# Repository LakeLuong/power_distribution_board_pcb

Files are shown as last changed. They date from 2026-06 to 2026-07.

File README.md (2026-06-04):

# power_distribution_board_pcb
Custom KiCad power distribution PCB that takes in +48V and regulates it down to 5V, 3.3V and 12V through two adjustable Lm760660 buck converters and a Tps62913. I made this for a bigger project I am working on for an underwater FPV drone to power different components such as ESCs which will take in +48V, sensors which takes 3.3V and 5V for my raspberry pi, and 12V for cameras. 





BOM: 

Tps62913	Low current buck converter converting 5V to 3.3V	2	$5.52		

Lm70660	High Current Buck Converter that takes 48V and brings it down to 12V and 5V	2	$13.60		

0805 4mOhm resistors	Current-sense resistors	10	$5.57	

0805 54.9k Ohm resistors	resistor connects from RT to AGND, helps with switching frequency	10	$0.37	

0806 20.5kOhm resistors	En Vulo resistors	10	$0.34	

0805 3.24kOhm resistor	Compensation capacitor for lm760660	10	$0.34	

0805 1 Ohm resistor	Bootstrap resistor	10	$0.51

0805 2.49kOhm resistor	feedback divider resistor	10	$0.34	

0805 4.87kOhm resistor	Feedback divider resistor	10	$0.34		

0805 52.3kOhm resistor	S-CONF resistor	10	$0.34	

0805 31.6kOhm resistor	Resistor divider for feedback	10	$0.58	

0805 100kOhm resistor	UVLO resistor, pull up resistors, etc, to control current flow	25	$0.64		

2.2uH inductor	Stores energy during switching and smooths current	3	$6.61	

Ferrite Bead	Blocks high frequency noise	5	$1.55	

0805 470nF Ceramic Capacitor	Reduce low frequency output noise on the Tps62913	10	$1.24	

0806 0.1uF Ceramic Capacitor	High frequency bypass capacitors	10	$1.07

0805 0.1uF Ceramic Capacitor	Decouples VDDA analog bias rail	10	$0.72	

0805 4.7uF Ceramic Capacitor	bypass/decoupling capacitor for VCC	5	$1.60	

0805 22uf Ceramic Capacitor	Smooths output voltage	10	$3.74	

1210 47uF Ceramic Capacitors	Smooths output voltage from regulator	15	$8.42	

0805 10uF Ceramic Capacitors	Input capacitors to provide short bursts of current to regulator	10	$3.48		

1210 4.7 uF Ceramic Capacitors	Input capacitors to provide short burst of current	10	$8.49		

0805 150pf Ceramic Capacitors	Compensation capacitors, helps buck converter stay stable from high frequency noise	10	$0.85		

1210 22uF Ceramic Capacitor	Gives high frequency noise to GND	10	$4.77

0805 10nF Ceramice Capacitors	bypass and filtering + provide positive power supply through VCC	10	$0.60	

0805 0.047 uF Ceramic Capacitor	Boostrap capacitor for buck converter	10	$1.47	

0805 2200pF SMD Ceramic Capacitor	Decoupling and filtering for 5v rail	10	$0.39

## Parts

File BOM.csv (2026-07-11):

Name | Purpose | Qty | Total (USD) | Unit Cost (USD) | Link | Distributor
Connectors | Connect to different components using physical wires | 10 | $9.55 | $0.9550 | https://www.digikey.com/en/products?keywords=Connectors | Digi-Key
Tps62913 | Low current buck converter converting 5V to 3.3V | 2 | $5.52 | $2.7600 | https://www.mouser.com/c/?q=Tps62913 | Mouser
Lm70660 | High Current Buck Converter that takes 48V and brings it down to 12V and 5V | 2 | $13.60 | $6.8000 | https://www.mouser.com/c/?q=Lm70660 | Mouser
0805 4mOhm resistors | Current-sense resistors | 10 | $5.57 | $0.5570 | https://www.digikey.com/en/products?keywords=0805+4mOhm+resistors | Digi-Key
0805 54.9k Ohm resistors | resistor connects from RT to AGND, helps with switching frequency | 10 | $0.37 | $0.0370 | https://www.digikey.com/en/products?keywords=0805+54.9k+Ohm+resistors | Digi-Key
0806 20.5kOhm resistors | En Vulo resistors | 10 | $0.34 | $0.0340 | https://www.digikey.com/en/products?keywords=0806+20.5kOhm+resistors | Digi-Key
0805 3.24kOhm resistor | Compensation capacitor for lm760660 | 10 | $0.34 | $0.0340 | https://www.digikey.com/en/products?keywords=0805+3.24kOhm+resistor | Digi-Key
0805 1 Ohm resistor | Bootstrap resistor | 10 | $0.51 | $0.0510 | https://www.digikey.com/en/products?keywords=0805+1+Ohm+resistor | Digi-Key
0805 2.49kOhm resistor | feedback divider resistor | 10 | $0.34 | $0.0340 | https://www.digikey.com/en/products?keywords=0805+2.49kOhm+resistor | Digi-Key
0805 4.87kOhm resistor | Feedback divider resistor | 10 | $0.34 | $0.0340 | https://www.digikey.com/en/products?keywords=0805+4.87kOhm+resistor | Digi-Key
0805 52.3kOhm resistor | S-CONF resistor | 10 | $0.34 | $0.0340 | https://www.digikey.com/en/products?keywords=0805+52.3kOhm+resistor | Digi-Key
0805 31.6kOhm resistor | Resistor divider for feedback | 10 | $0.58 | $0.0580 | https://www.digikey.com/en/products?keywords=0805+31.6kOhm+resistor | Digi-Key
0805 100kOhm resistor | UVLO resistor, pull up resistors, etc, to control current flow | 25 | $0.64 | $0.0256 | https://www.digikey.com/en/products?keywords=0805+100kOhm+resistor | Digi-Key
2.2uH inductor | Stores energy during switching and smooths current | 3 | $6.61 | $2.2033 | https://www.coilcraft.com/en-us/search/?text=2.2uH+inductor | Coilcraft
Ferrite Bead | Blocks high frequency noise | 5 | $1.55 | $0.3100 | https://www.digikey.com/en/products?keywords=Ferrite+Bead | Digi-Key
0805 470nF Ceramic Capacitor | Reduce low frequency output noise on the Tps62913 | 10 | $1.24 | $0.1240 | https://www.digikey.com/en/products?keywords=0805+470nF+Ceramic+Capacitor | Digi-Key
0806 0.1uF Ceramic Capacitor | High frequency bypass capacitors | 10 | $1.07 | $0.1070 | https://www.digikey.com/en/products?keywords=0806+0.1uF+Ceramic+Capacitor | Digi-Key
0805 0.1uF Ceramic Capacitor | Decouples VDDA analog bias rail | 10 | $0.72 | $0.0720 | https://www.digikey.com/en/products?keywords=0805+0.1uF+Ceramic+Capacitor | Digi-Key
0805 4.7uF Ceramic Capacitor | bypass/decoupling capacitor for VCC | 5 | $1.60 | $0.3200 | https://www.digikey.com/en/products?keywords=0805+4.7uF+Ceramic+Capacitor | Digi-Key
0805 22uf Ceramic Capacitor | Smooths output voltage | 10 | $3.74 | $0.3740 | https://www.digikey.com/en/products?keywords=0805+22uf+Ceramic+Capacitor | Digi-Key
1210 47uF Ceramic Capacitors | Smooths output voltage from regulator | 15 | $8.42 | $0.5613 | https://www.digikey.com/en/products?keywords=1210+47uF+Ceramic+Capacitors | Digi-Key
0805 10uF Ceramic Capacitors | Input capacitors to provide short bursts of current to regulator | 10 | $3.48 | $0.3480 | https://www.digikey.com/en/products?keywords=0805+10uF+Ceramic+Capacitors | Digi-Key
1210 4.7 uF Ceramic Capacitors | Input capacitors to provide short burst of current | 10 | $8.49 | $0.8490 | https://www.digikey.com/en/products?keywords=1210+4.7+uF+Ceramic+Capacitors | Digi-Key
0805 150pf Ceramic Capacitors | Compensation capacitors, helps buck converter stay stable from high frequency noise | 10 | $0.85 | $0.0850 | https://www.digikey.com/en/products?keywords=0805+150pf+Ceramic+Capacitors | Digi-Key
1210 22uF Ceramic Capacitor | Gives high frequency noise to GND | 10 | $4.77 | $0.4770 | https://www.digikey.com/en/products?keywords=1210+22uF+Ceramic+Capacitor | Digi-Key
0805 10nF Ceramice Capacitors | bypass and filtering + provide positive power supply through VCC | 10 | $0.60 | $0.0600 | https://www.digikey.com/en/products?keywords=0805+10nF+Ceramice+Capacitors | Digi-Key
0805 0.047 uF Ceramic Capacitor | Boostrap capacitor for buck converter | 10 | $1.47 | $0.1470 | https://www.digikey.com/en/products?keywords=0805+0.047+uF+Ceramic+Capacitor | Digi-Key
0805 2200pF SMD Ceramic Capacitor | Decoupling and filtering for 5v rail | 10 | $0.39 | $0.0390 | https://www.digikey.com/en/products?keywords=0805+2200pF+SMD+Ceramic+Capacitor | Digi-Key

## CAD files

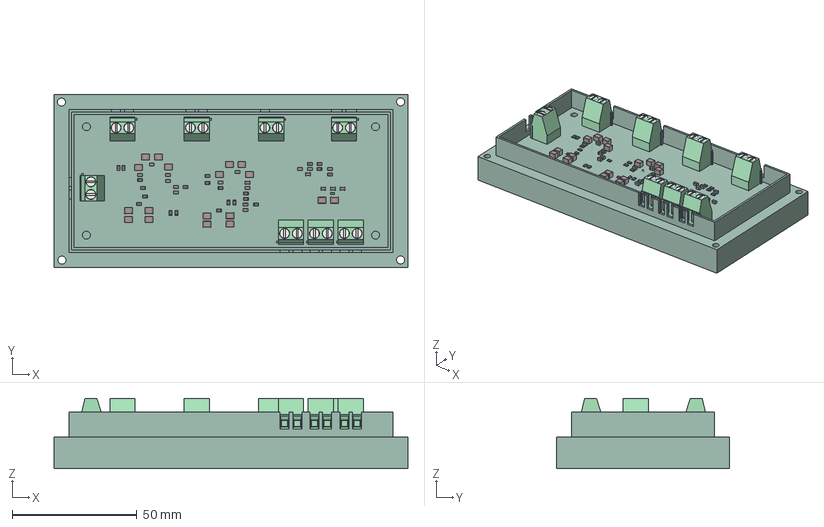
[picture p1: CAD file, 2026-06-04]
CAD/Board.step
142.0 x 69.4 x 28.1 mm
R_0805_2012Metric x 22
C_0805_2012Metric x 19
L_0603_1608Metric
C_1210_3225Metric x 18
TerminalBlock_Phoenix_MKDS-1,5-2-5.08_1x02_P5.08mm_Horizontal x 8
power_distribution_board_pcb_v2_PCB

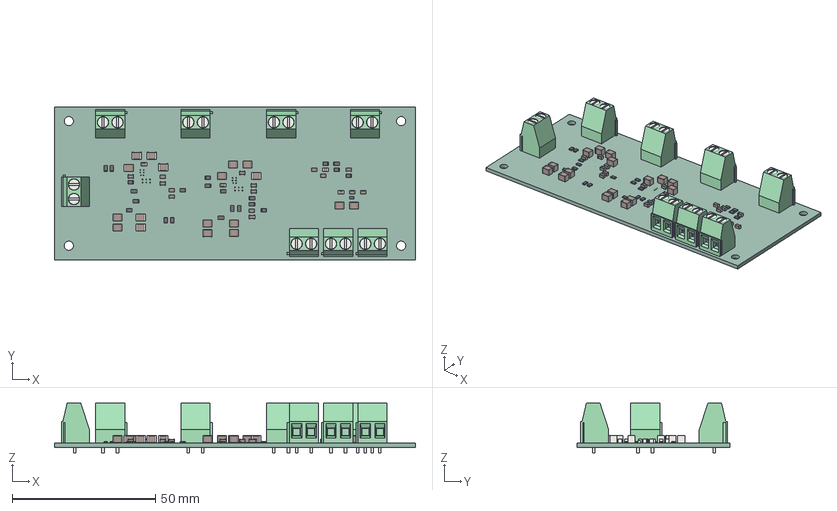
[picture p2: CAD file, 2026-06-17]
power_distribution_board_pcb_v2-2026-04-06_225556/.step
126.0 x 53.4 x 17.3 mm
R_0805_2012Metric x 22
C_1210_3225Metric x 18
C_0805_2012Metric x 19
TerminalBlock_Phoenix_MKDS-1,5-2-5.08_1x02_P5.08mm_Horizontal x 8
L_0603_1608Metric
power_distribution_board_pcb_v2_PCB

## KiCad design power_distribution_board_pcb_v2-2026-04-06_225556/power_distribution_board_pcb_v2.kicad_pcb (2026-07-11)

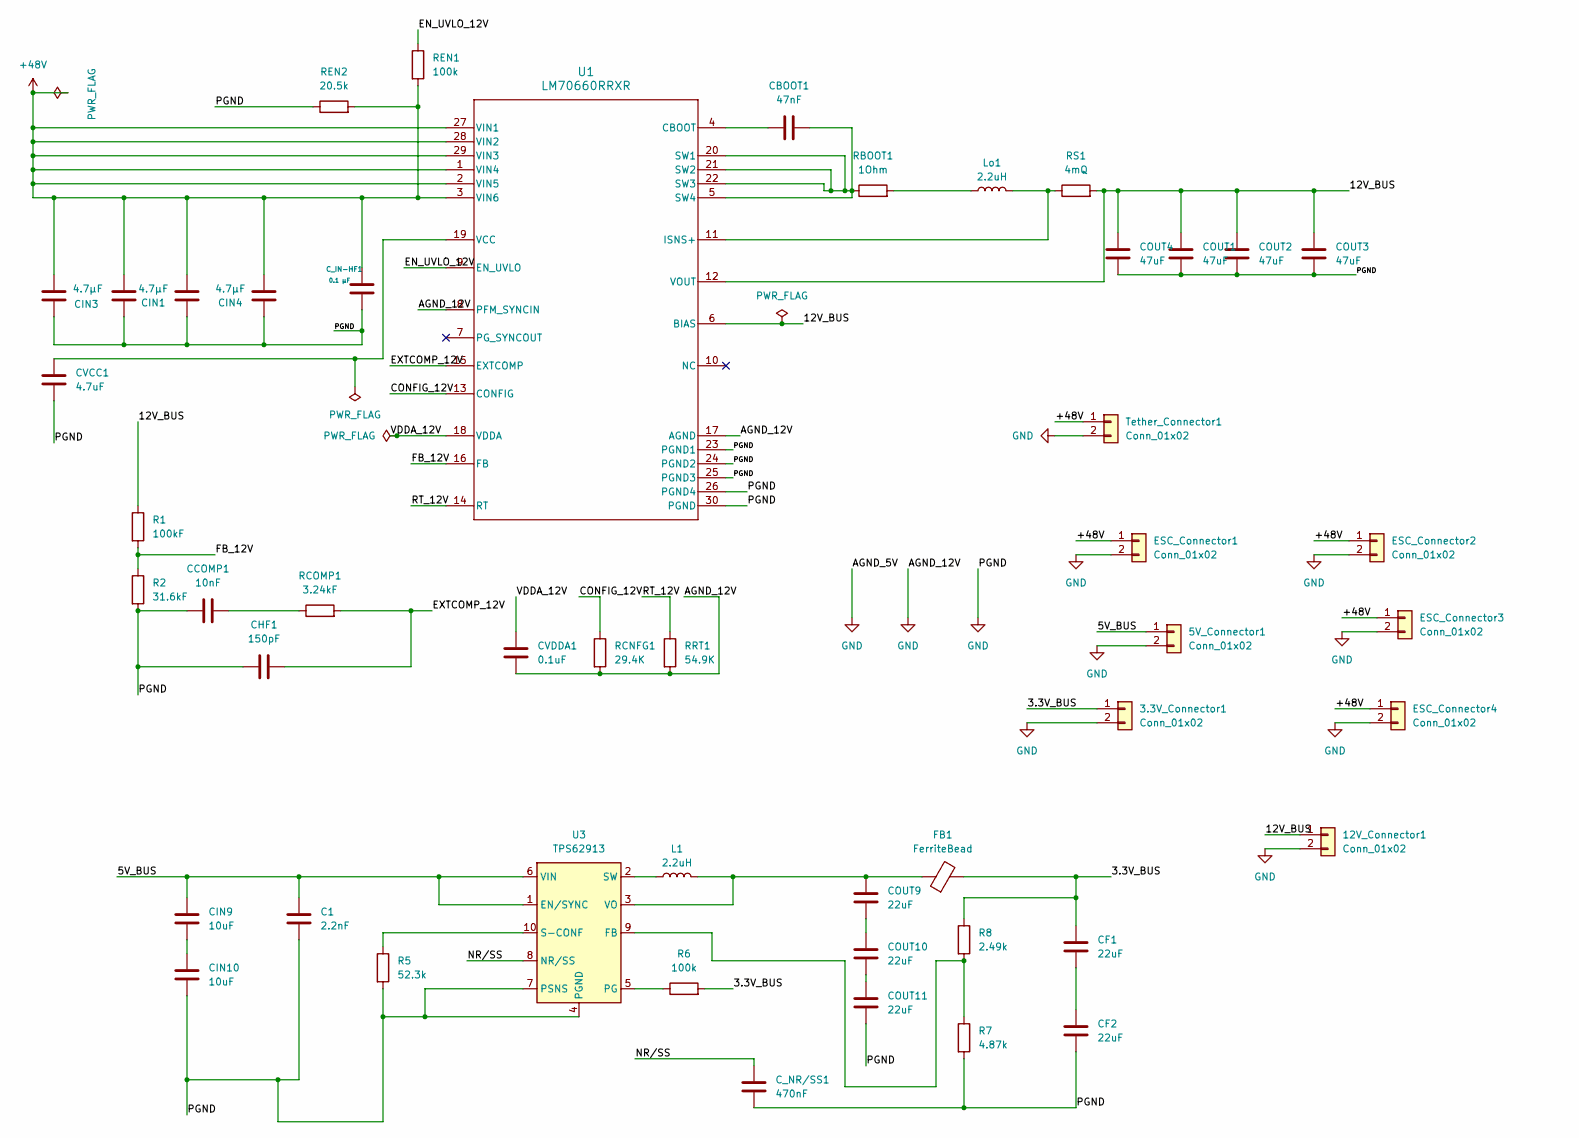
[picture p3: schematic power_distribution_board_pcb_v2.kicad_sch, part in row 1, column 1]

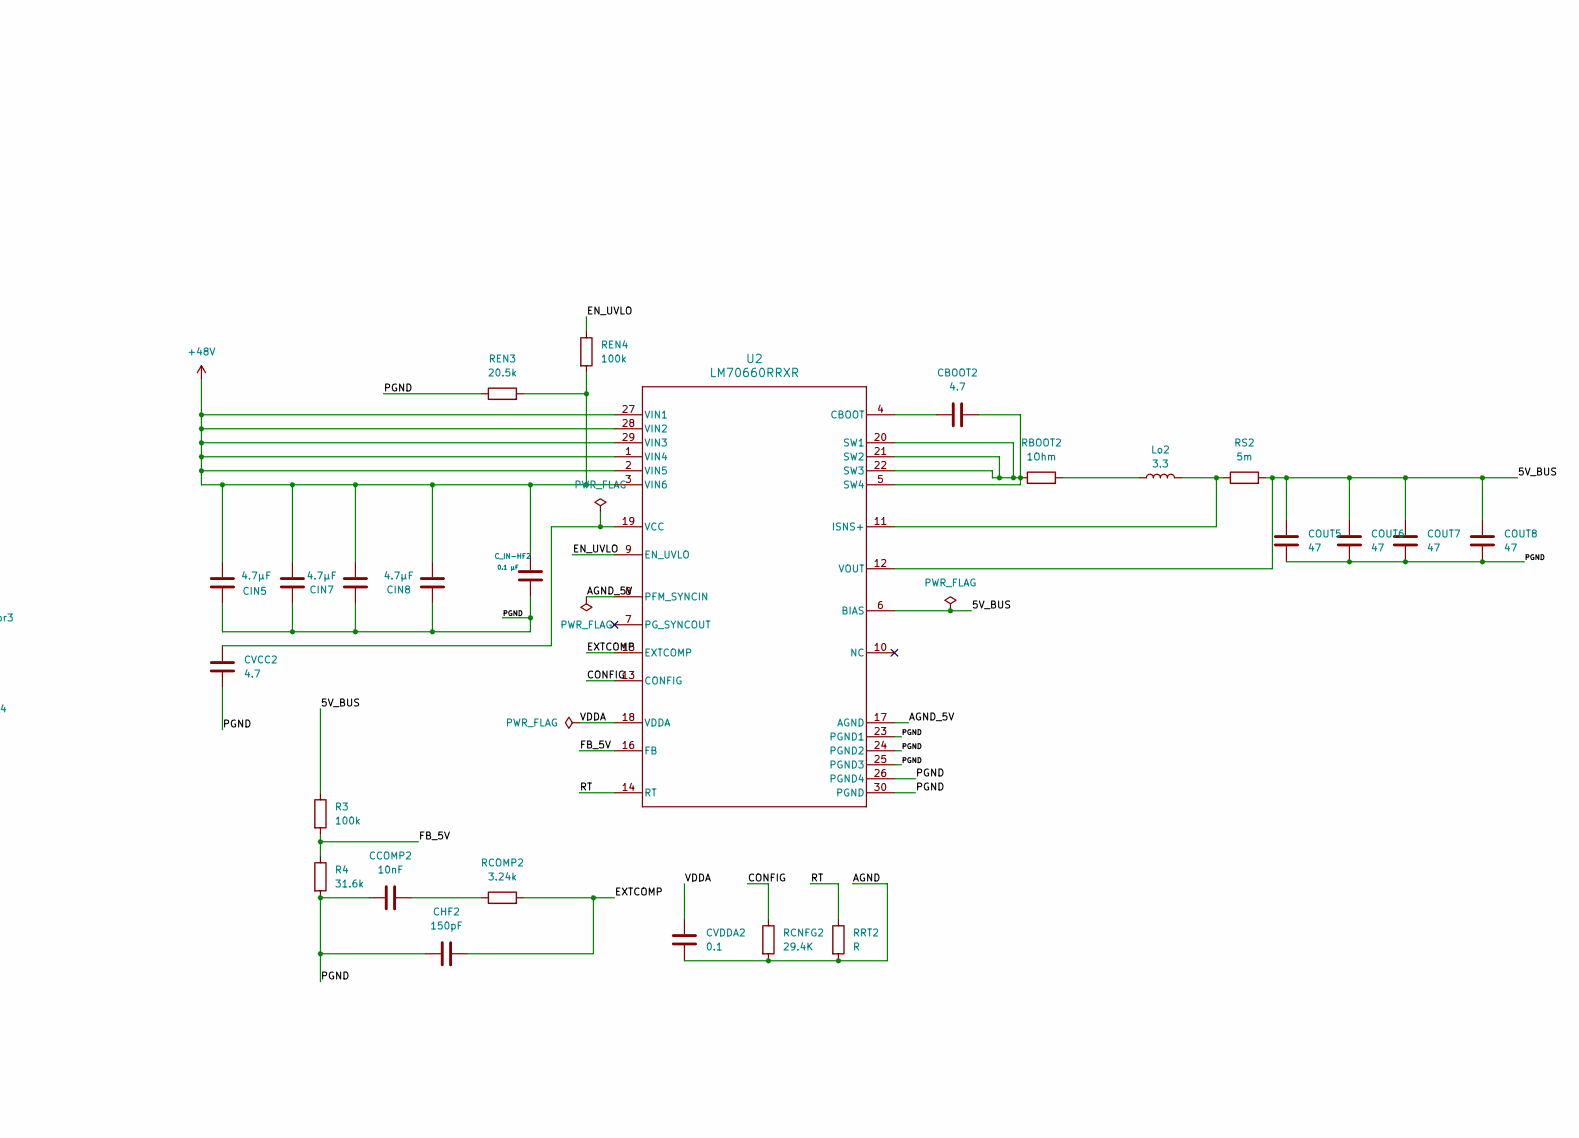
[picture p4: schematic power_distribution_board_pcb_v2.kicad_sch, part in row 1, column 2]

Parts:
3.3V_Connector1, 5V_Connector1, 12V_Connector1: Conn_01x02; TerminalBlock_Phoenix_MKDS-1,5-2-5.08_1x02_P5.08mm_Horizont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
C1: 2.2nF; C_0805_2012Metric_Pad1.18x1.45mm_HandSolder
CBOOT1: 47nF; C_0805_2012Metric_Pad1.18x1.45mm_HandSolder
CBOOT2: 4.7; C_0805_2012Metric_Pad1.18x1.45mm_HandSolder
CCOMP1, CCOMP2: 10nF; C_0805_2012Metric_Pad1.18x1.45mm_HandSolder
CF1, CF2: 22uF; C_1210_3225Metric_Pad1.33x2.70mm_HandSolder
CHF1, CHF2: 150pF; C_0805_2012Metric_Pad1.18x1.45mm_HandSolder
CIN1, CIN2, CIN3, CIN4, CIN5, CIN6, CIN7, CIN8: 4.7µF; C_1210_3225Metric_Pad1.33x2.70mm_HandSolder
CIN9, CIN10: 10uF; C_0805_2012Metric_Pad1.18x1.45mm_HandSolder
COUT1, COUT2, COUT3, COUT4: 47uF; C_1210_3225Metric_Pad1.33x2.70mm_HandSolder
COUT5, COUT6, COUT7, COUT8: 47; C_1210_3225Metric_Pad1.33x2.70mm_HandSolder
COUT9, COUT10, COUT11: 22uF; C_0805_2012Metric_Pad1.18x1.45mm_HandSolder
CVCC1: 4.7uF; C_0805_2012Metric_Pad1.18x1.45mm_HandSolder
CVCC2: 4.7; C_0805_2012Metric_Pad1.18x1.45mm_HandSolder
CVDDA1: 0.1uF; C_0805_2012Metric_Pad1.18x1.45mm_HandSolder
CVDDA2: 0.1; C_0805_2012Metric_Pad1.18x1.45mm_HandSolder
C_IN-HF1, C_IN-HF2: 0.1 µF; C_0805_2012Metric_Pad1.18x1.45mm_HandSolder
C_NR/SS1: 470nF; C_0805_2012Metric_Pad1.18x1.45mm_HandSolder
ESC_Connector1, ESC_Connector2, ESC_Connector3, ESC_Connector4: Conn_01x02; TerminalBlock_Phoenix_MKDS-1,5-2-5.08_1x02_P5.08mm_Horizont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
FB1: FerriteBead; L_0603_1608Metric_Pad1.05x0.95mm_HandSolder
L1: 2.2uH; IND_XGL4030_COC-M
Lo1: 2.2uH; IND_XGL4030_COC-M
Lo2: 3.3; IND_XGL4030_COC-M
R1: 100kF; R_0805_2012Metric_Pad1.20x1.40mm_HandSolder
R2: 31.6kF; R_0805_2012Metric_Pad1.20x1.40mm_HandSolder
R3, R6: 100k; R_0805_2012Metric_Pad1.20x1.40mm_HandSolder
R4: 31.6k; R_0805_2012Metric_Pad1.20x1.40mm_HandSolder
R5: 52.3k; R_0805_2012Metric_Pad1.20x1.40mm_HandSolder
R7: 4.87k; R_0805_2012Metric_Pad1.20x1.40mm_HandSolder
R8: 2.49k; R_0805_2012Metric_Pad1.20x1.40mm_HandSolder
RBOOT1, RBOOT2: 1Ohm; R_0805_2012Metric_Pad1.20x1.40mm_HandSolder
RCNFG1, RCNFG2: 29.4K; R_0805_2012Metric_Pad1.20x1.40mm_HandSolder
RCOMP1: 3.24kF; R_0805_2012Metric_Pad1.20x1.40mm_HandSolder
RCOMP2: 3.24k; R_0805_2012Metric_Pad1.20x1.40mm_HandSolder
REN1, REN4: 100k; R_0805_2012Metric_Pad1.20x1.40mm_HandSolder
REN2, REN3: 20.5k; R_0805_2012Metric_Pad1.20x1.40mm_HandSolder
RRT1: 54.9K; R_0805_2012Metric_Pad1.20x1.40mm_HandSolder
RRT2: R; R_0805_2012Metric_Pad1.20x1.40mm_HandSolder
RS1: 4mQ; R_0805_2012Metric_Pad1.20x1.40mm_HandSolder
RS2: 5m; R_0805_2012Metric_Pad1.20x1.40mm_HandSolder
Tether_Connector1: Conn_01x02; TerminalBlock_Phoenix_MKDS-1,5-2-5.08_1x02_P5.08mm_Horizont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
U1, U2: LM70660RRXR; RRX0029B-MFG
U3: TPS62913; Texas_RPU0010A_VQFN-HR-10_2x2mm_P0.5mm

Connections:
+48V: CIN1.2, CIN2.2, CIN3.1, CIN4.2, CIN5.1, CIN6.2, CIN7.2, CIN8.2, C_IN-HF1.1, C_IN-HF2.1, ESC_Connector1.1, ESC_Connector2.1, ESC_Connector3.1, ESC_Connector4.1, REN1.2, REN2.2, REN3.2, REN4.2, Tether_Connector1.1, U1.1 (VIN4), U1.2 (VIN5), U1.3 (VIN6), U1.27 (VIN1), U1.28 (VIN2), U1.29 (VIN3), U1.37, U1.38, U1.39, U1.40, U1.41, U1.42, U2.1 (VIN4), U2.2 (VIN5), U2.3 (VIN6), U2.27 (VIN1), U2.28 (VIN2), U2.29 (VIN3), U2.37, U2.38, U2.39, U2.40, U2.41
/3.3V_BUS: 3.3V_Connector1.1, CF1.1, FB1.2, R6.2, R8.1
/AGND: CVDDA2.2, RCNFG2.2, RRT2.2
/CONFIG: RCNFG2.1, U2.13 (CONFIG)
/CONFIG_12V: RCNFG1.1, U1.13 (CONFIG)
/EN_UVLO: REN4.1, U2.9 (EN_UVLO)
/EN_UVLO_12V: REN1.1, U1.9 (EN_UVLO)
/EXTCOMP: CHF2.2, RCOMP2.2, U2.15 (EXTCOMP)
/EXTCOMP_12V: CHF1.2, RCOMP1.2, U1.15 (EXTCOMP)
/FB_5V: R3.2, R4.1, U2.16 (FB)
/FB_12V: R1.2, R2.1, U1.16 (FB)
/NR/SS: C_NR/SS1.2, U3.8 (NR/SS)
/RT: RRT2.1, U2.14 (RT)
/RT_12V: RRT1.1, U1.14 (RT)
/VDDA: CVDDA2.1, U2.18 (VDDA)
/VDDA_12V: CVDDA1.1, U1.18 (VDDA)
GND: 3.3V_Connector1.2, 5V_Connector1.2, 12V_Connector1.2, C1.2, CCOMP1.1, CCOMP2.1, CF2.2, CHF1.1, CHF2.1, CIN1.1, CIN2.1, CIN3.2, CIN4.1, CIN5.2, CIN6.1, CIN7.1, CIN8.1, CIN10.2, COUT1.2, COUT2.2, COUT3.2, COUT4.2, COUT5.2, COUT6.2, COUT7.2, COUT8.2, COUT11.2, CVCC1.2, CVCC2.2, CVDDA1.2, C_IN-HF1.2, C_IN-HF2.2, C_NR/SS1.1, ESC_Connector1.2, ESC_Connector2.2, ESC_Connector3.2, ESC_Connector4.2, R2.2, R4.2, R5.2, R7.2, RCNFG1.2, REN2.1, REN3.1, RRT1.2, Tether_Connector1.2, U1.8 (PFM_SYNCIN), U1.17 (AGND), U1.23 (PGND1), U1.24 (PGND2), U1.25 (PGND3), U1.26 (PGND4), U1.30 (PGND), U1.31, U1.32, U1.33, U1.34, U1.35, U1.36, U2.8 (PFM_SYNCIN), U2.17 (AGND), U2.23 (PGND1), U2.24 (PGND2), U2.25 (PGND3), U2.26 (PGND4), U2.30 (PGND), U2.31, U2.32, U2.33, U2.34, U2.35, U2.36, U3.4 (PGND), U3.7 (PSNS)
unnamed: CCOMP1.2, RCOMP1.1
unnamed: CCOMP2.2, RCOMP2.1
unnamed: CF1.2, CF2.1
unnamed: CIN9.2, CIN10.1
unnamed: COUT9.2, COUT10.1
unnamed: COUT10.2, COUT11.1
unnamed: Lo1.1, RBOOT1.2
unnamed: Lo2.1, RBOOT2.2
unnamed: CBOOT1.1, U1.4 (CBOOT)
unnamed: Lo1.2, RS1.1, U1.11 (ISNS+)
unnamed: CBOOT1.2, RBOOT1.1, U1.5 (SW4), U1.20 (SW1), U1.21 (SW2), U1.22 (SW3)
unnamed: CVCC1.1, U1.19 (VCC)
unnamed: CBOOT2.1, U2.4 (CBOOT)
unnamed: Lo2.2, RS2.1, U2.11 (ISNS+)
unnamed: CBOOT2.2, RBOOT2.1, U2.5 (SW4), U2.20 (SW1), U2.21 (SW2), U2.22 (SW3)
unnamed: CVCC2.1, U2.19 (VCC)
unnamed: R7.1, R8.2, U3.9 (FB)
unnamed: R6.1, U3.5 (PG)
unnamed: R5.1, U3.10 (S-CONF)
unnamed: L1.1, U3.2 (SW)
unnamed: COUT9.1, FB1.1, L1.2, U3.3 (VO)

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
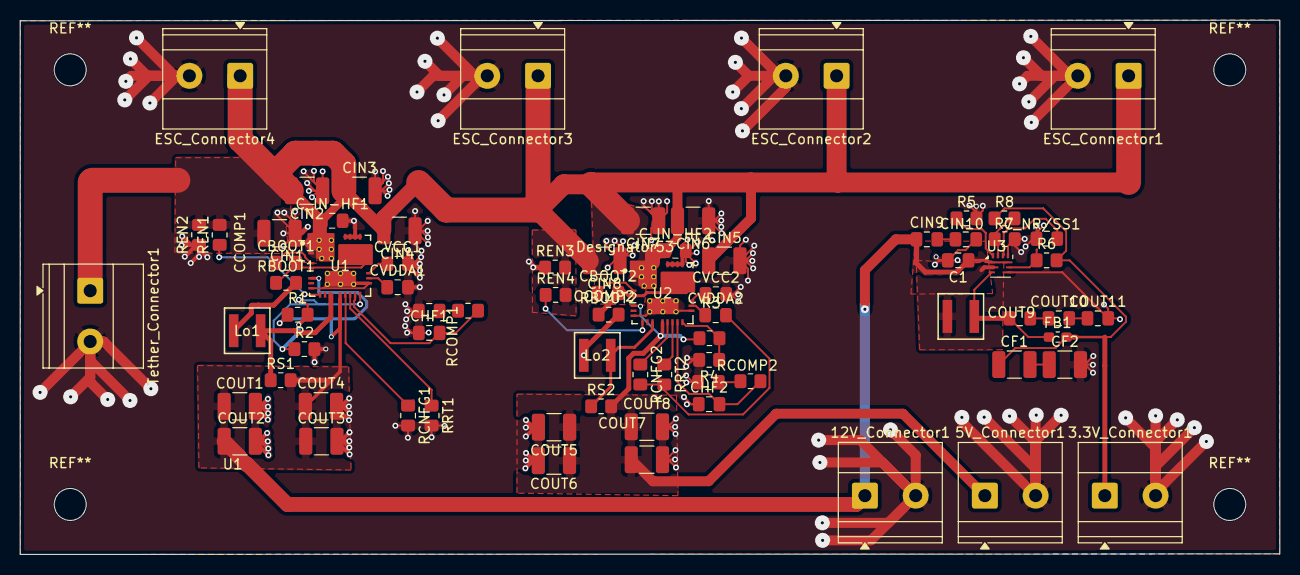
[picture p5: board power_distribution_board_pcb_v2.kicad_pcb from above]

Board: 2 copper layers, 126.0 x 53.4 mm, 74 parts (0 on the bottom side), 40 nets.

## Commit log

2026-03-28 Added buck converter datasheet
2026-03-30 Added new datasheet for low noise voltage regulator
2026-04-01 added schematic and footprint
2026-04-03 Added project files
    [power_distribution_project_file.kicad_pcb, power_distribution_project_file.kicad_sch]
2026-04-07 Added version 2 of the pcb schematic
    [power_distribution_board_pcb_v2.kicad_pcb, power_distribution_board_pcb_v2.kicad_sch]
2026-06-03 Update KiCad project files
    [${PowerDistributionBoard}.csv, power_distribution_board_pcb_v2.kicad_pcb, power_distribution_board_pcb_v2.kicad_sch]
2026-06-03 moved files
    [${PowerDistributionBoard}.csv]
2026-06-03 Revise README description for power distribution PCB
    Updated project description to specify input voltage and output regulation details.
2026-06-04 Added step file
    [step 1.step]
2026-06-04 Update README with component specifications and costs and BOM
    Added detailed component list with descriptions and pricing.
2026-06-04 Fix BOM formatting in README.md
2026-06-04 Move STEP file into CAD folder
    [step 1.step]
2026-06-17 update pcb and schematic
    [.step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]
2026-07-11 Add power distribution board files
    [pdb_order_list_with_costs.csv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]
2026-07-12 reaaranged filels
    [.step, BOM.csv, Board.step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]
